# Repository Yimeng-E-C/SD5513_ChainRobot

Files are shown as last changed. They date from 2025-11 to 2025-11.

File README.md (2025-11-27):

# SD5513_ChainRobot
## 项目简介

**[ChainRobot]** 是一个用于 **[SD5513课程入门]** 的开源项目。  
本仓库包含完整的源代码、配置文件以及基础文档，方便开发者快速上手与二次开发。
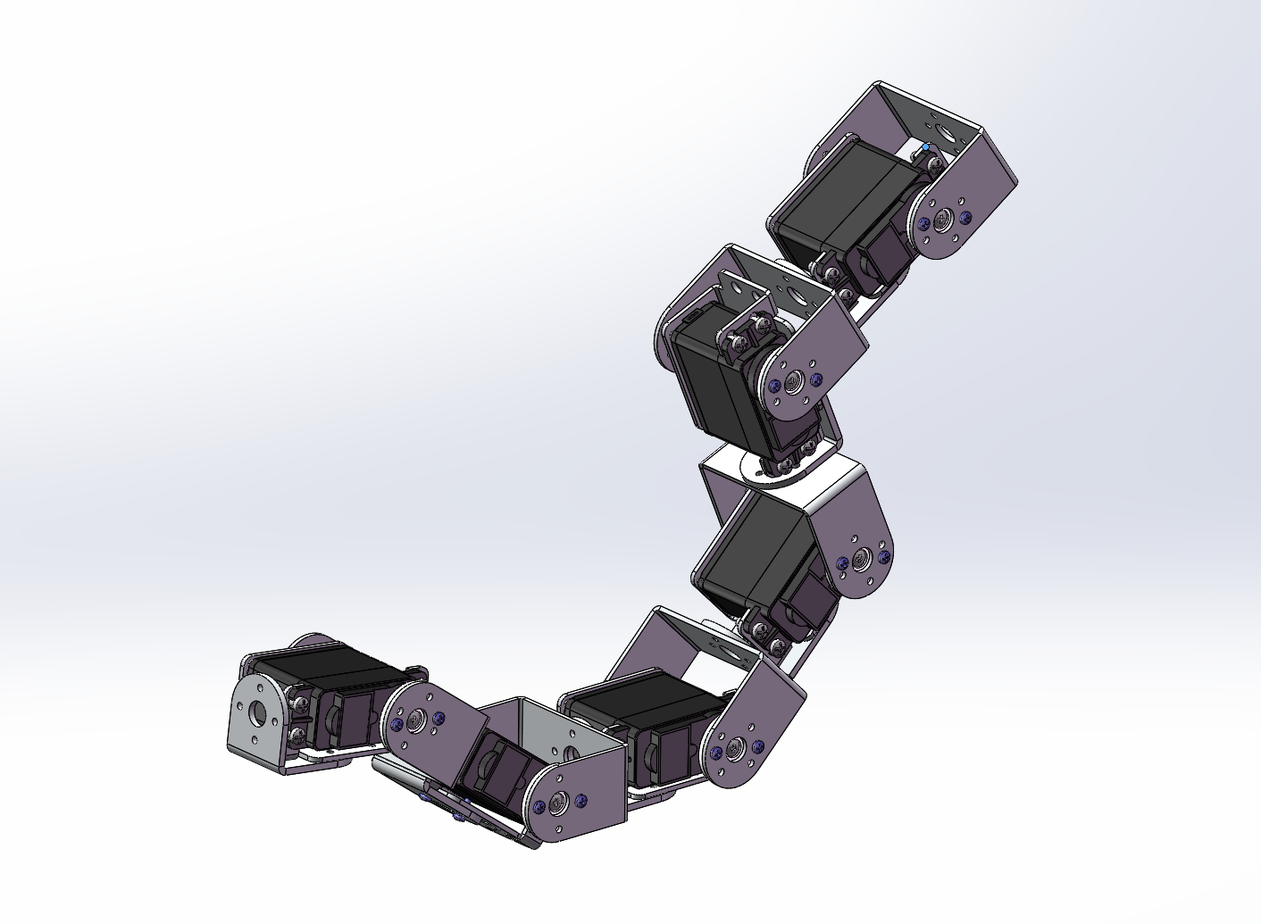
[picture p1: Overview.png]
Overview
- 

### 功能概览

- ✅ **核心功能 1**：用于 **[例如：数据处理 / 模型训练 / 设备控制等]**
- ✅ **核心功能 2**：支持 **[例如：可视化 / 实时监控 / 接口调用等]**
- ✅ **核心功能 3**：提供 **[例如：命令行工具 / Web 界面 / API 接口]**

### 技术栈

- 语言：**[例如：Python / JavaScript / C++ 等]**
- 框架 / 库：**[例如：PyTorch / React / Node.js / ROS 等]**
- 其他：**[例如：Docker / MQTT / REST API 等]**
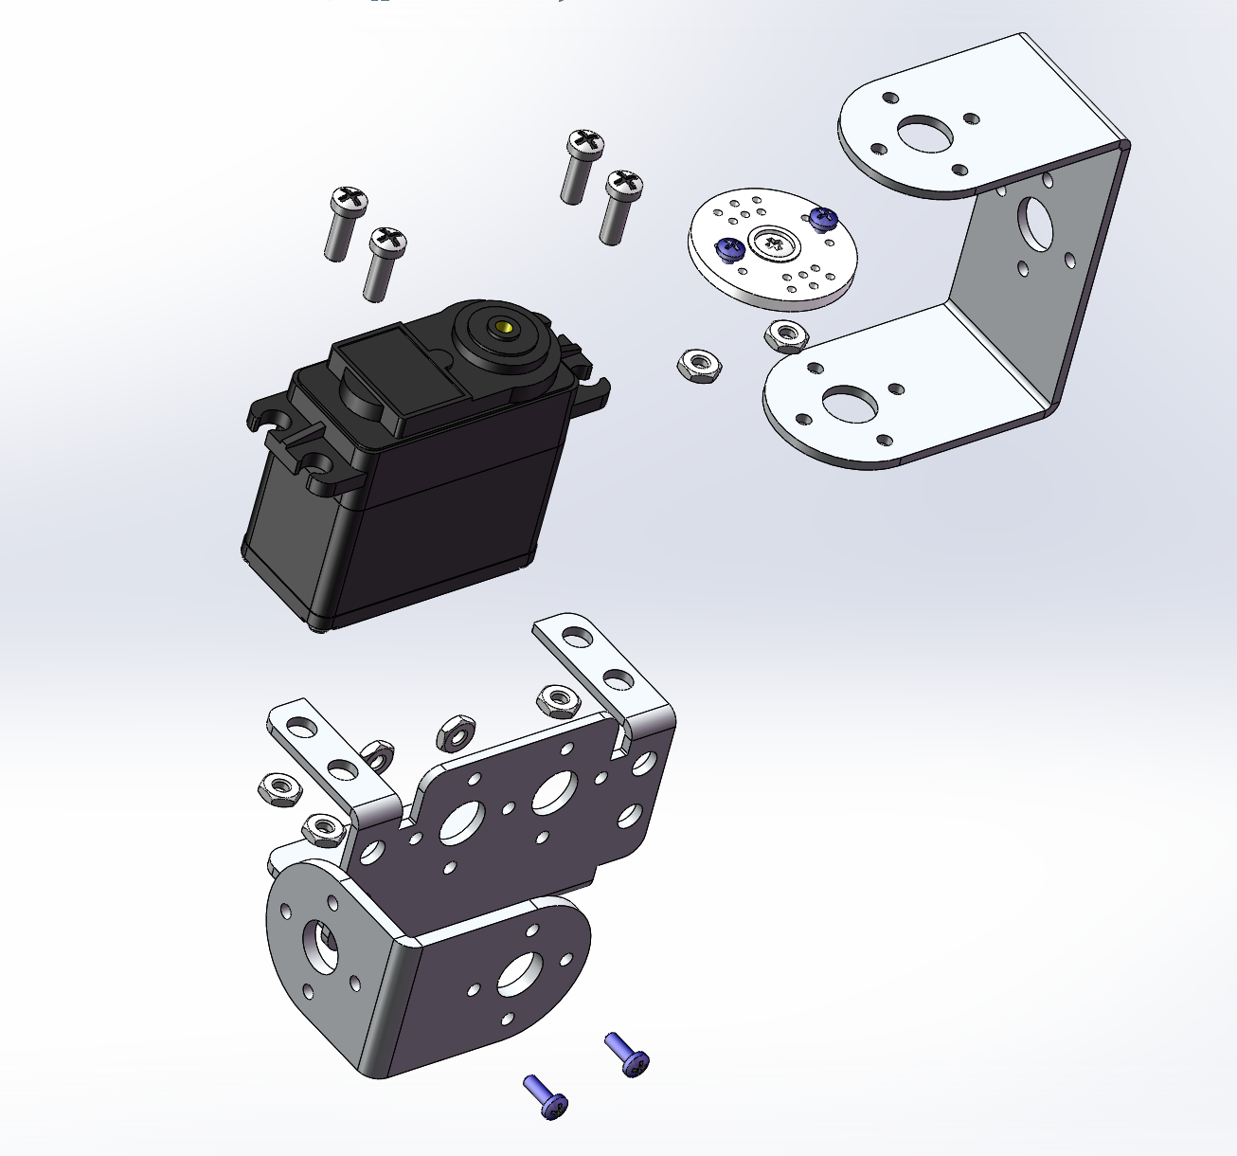
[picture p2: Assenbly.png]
Assenbly
- 

### 适用场景

本项目适用于：

- **[场景 1]**：如 *[示例]*  
- **[场景 2]**：如 *[示例]*  
- **[场景 3]**：如 *[示例]*  

### 快速开始

如果你想快速体验本项目，可以参考下方章节：

- 控制代码：见 **[Instruction / 指导]** 部分  
- 硬件组装：见 **[Models / Assenbly]** 部分  
- 更多细节：见 **[Docs / 文档链接或路径]**

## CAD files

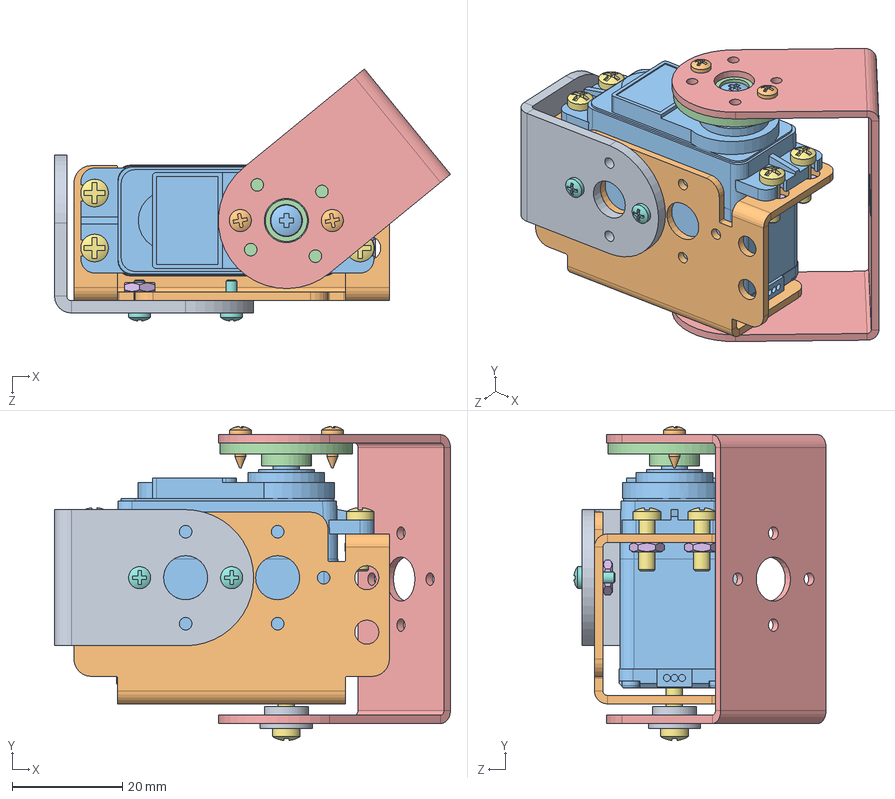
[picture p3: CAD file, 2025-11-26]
Models/Unit1.SLDASM
71.7 x 56.9 x 45.7 mm
Servo-HS-485HB
ASB-04
ASB-06
Bolt-01 x 2
Bolt-02 x 5
Nut-02 x 5
ASB-09
Servo-Dial
Servo-Screw
Screw-01 x 2
Ball-Bearing-01

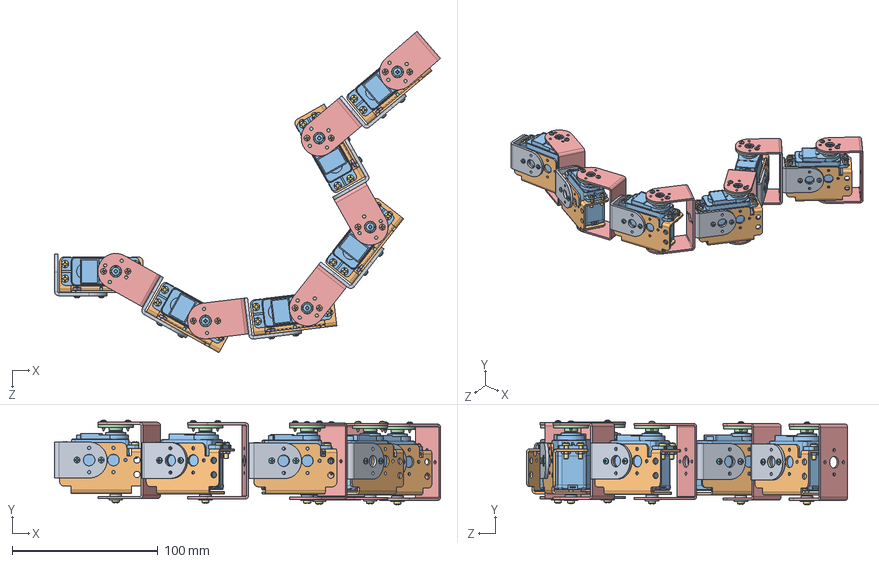
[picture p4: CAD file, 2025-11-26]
Models/SnakeRobot.SLDASM
264.6 x 58.1 x 220.4 mm
Servo-HS-485HB x 6
ASB-04 x 6
ASB-06 x 6
Bolt-01 x 12
Bolt-02 x 30
Nut-02 x 30
ASB-09 x 6
Servo-Dial x 6
Servo-Screw x 6
Screw-01 x 12
Ball-Bearing-01 x 6

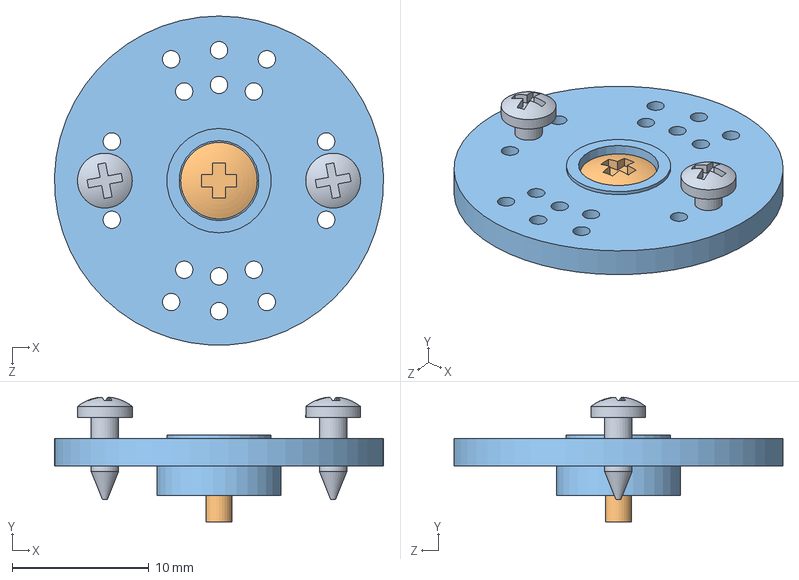
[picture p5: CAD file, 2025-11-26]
Models/SERVO-DIAL-ASSEMBLY.SLDASM
24.0 x 9.09 x 24.0 mm
Servo-Dial
Servo-Screw
Screw-01 x 2

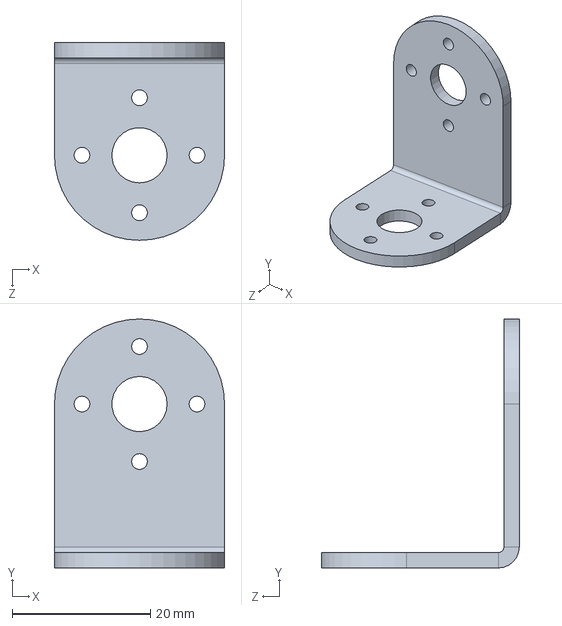
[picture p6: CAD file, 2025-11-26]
Models/ASB-06.SLDPRT
24.6 x 36.1 x 28.6 mm

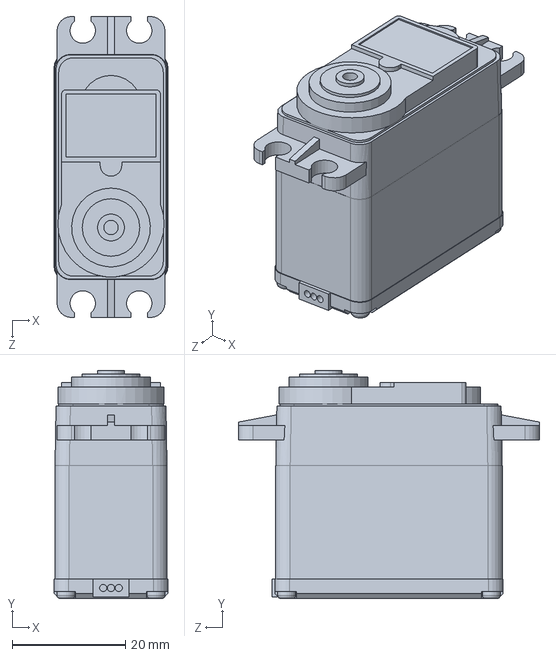
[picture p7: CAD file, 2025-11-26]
Models/Servo-HS-485HB.SLDPRT
20.1 x 40.2 x 53.1 mm

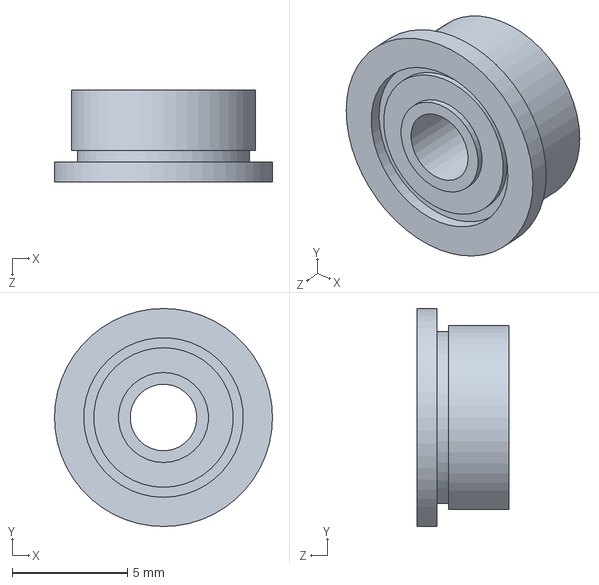
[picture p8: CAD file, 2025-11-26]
Models/Ball-Bearing-01.SLDPRT
9.47 x 9.47 x 3.99 mm

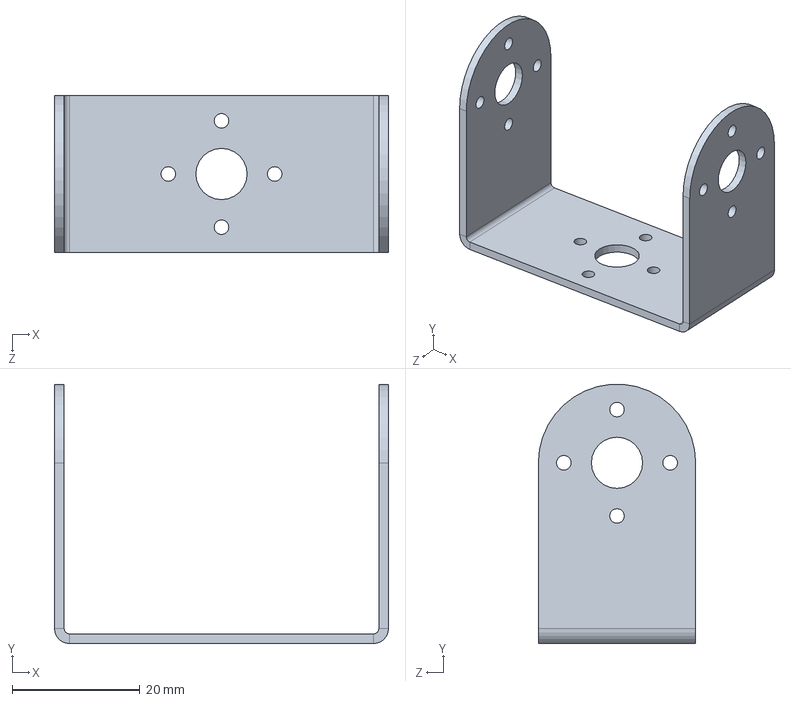
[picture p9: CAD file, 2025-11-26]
Models/ASB-09.SLDPRT
52.3 x 40.6 x 24.6 mm

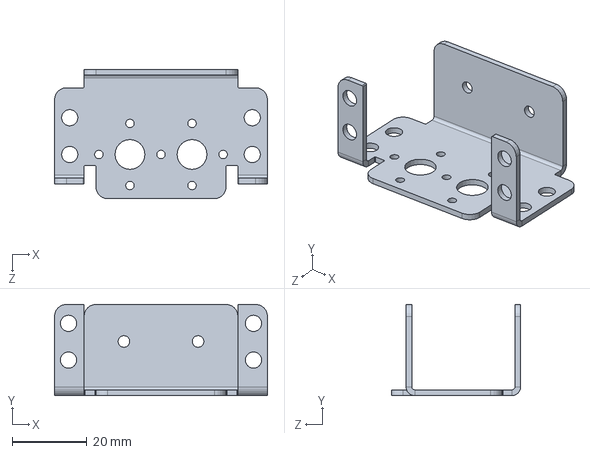
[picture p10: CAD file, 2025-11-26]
Models/ASB-04.SLDPRT
57.1 x 24.5 x 34.7 mm

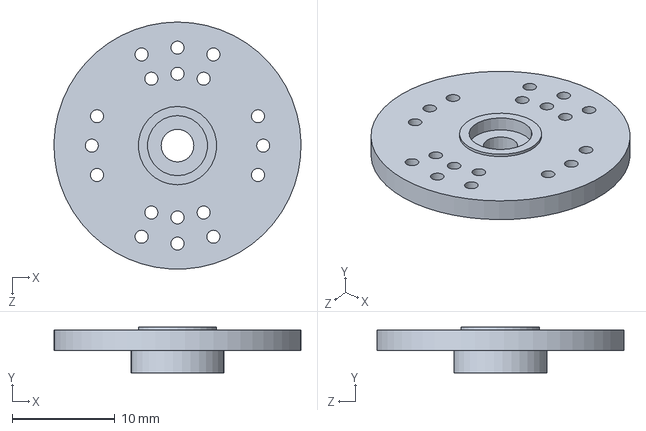
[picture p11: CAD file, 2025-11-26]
Models/Servo-Dial.SLDPRT
24.0 x 4.45 x 24.0 mm

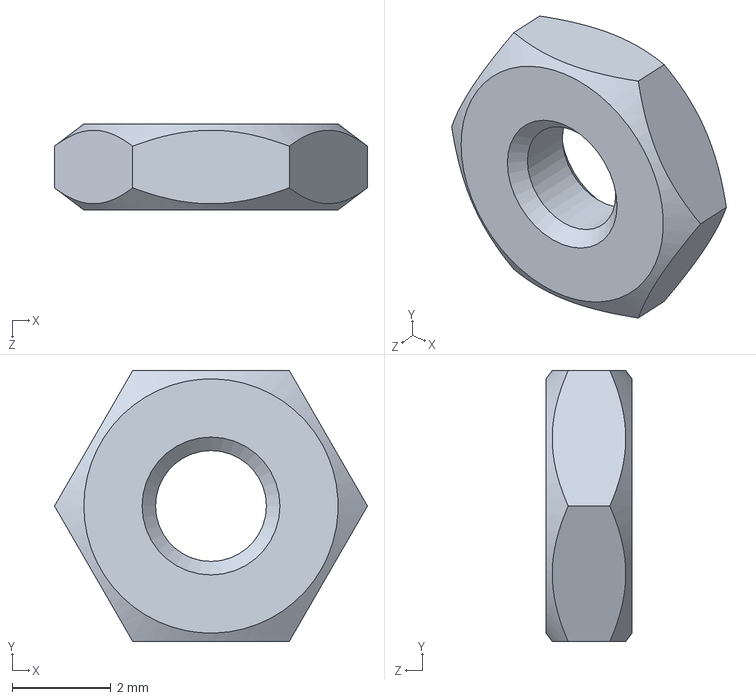
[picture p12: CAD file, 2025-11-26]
Models/Nut-02.SLDPRT
6.35 x 5.50 x 1.75 mm

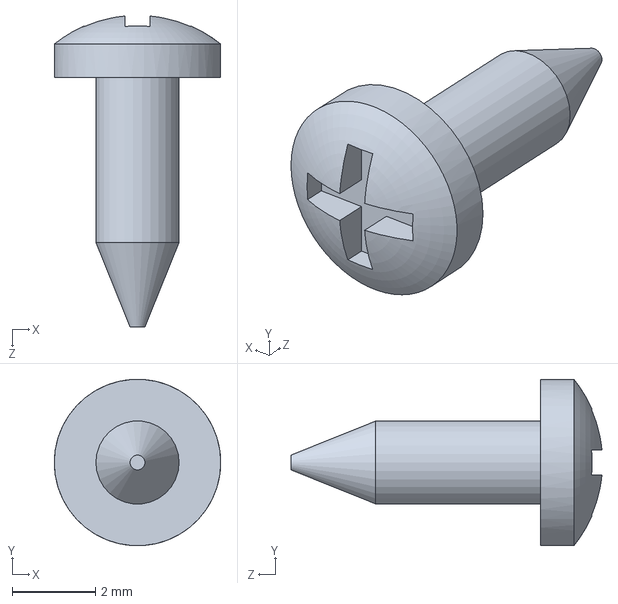
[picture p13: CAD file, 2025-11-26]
Models/Screw-01.SLDPRT
4.00 x 4.00 x 7.47 mm

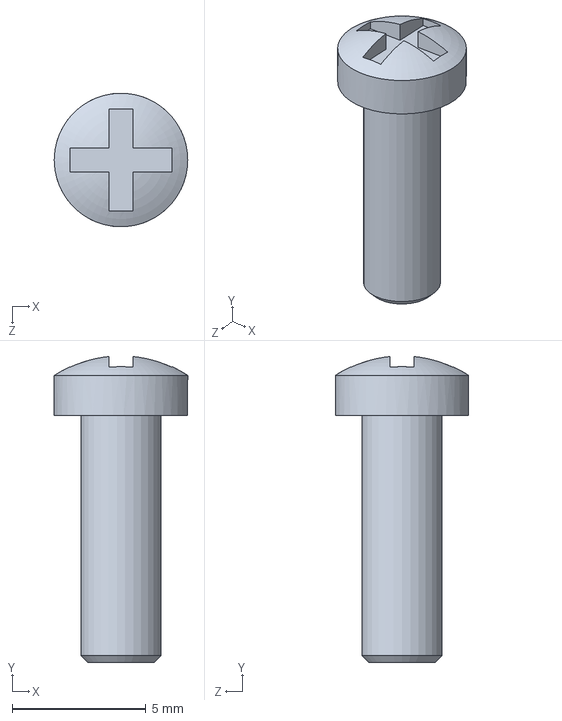
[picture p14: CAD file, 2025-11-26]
Models/Bolt-02.SLDPRT
5.00 x 11.5 x 5.00 mm

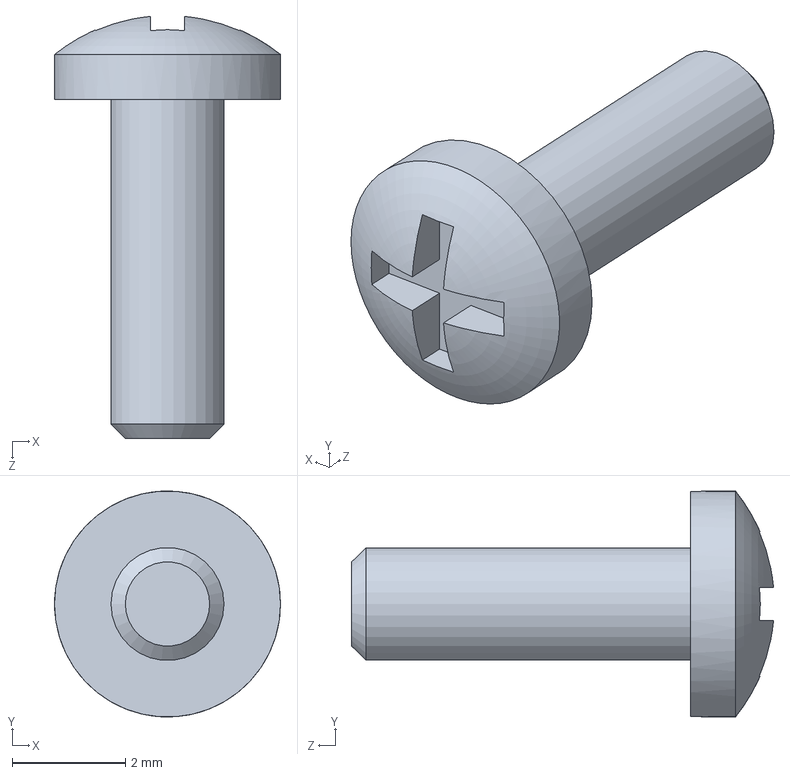
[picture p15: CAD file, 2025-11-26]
Models/Bolt-01.SLDPRT
4.00 x 4.00 x 7.47 mm

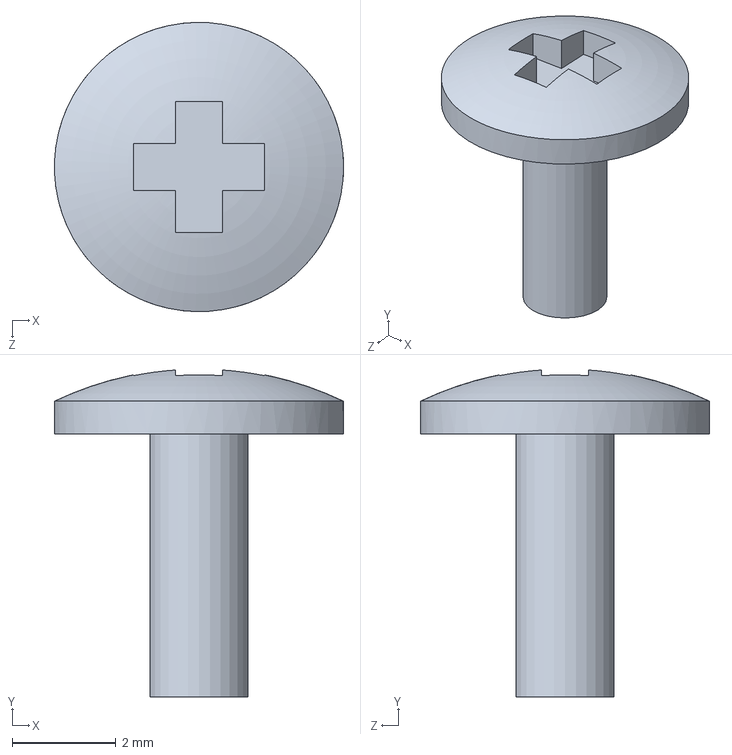
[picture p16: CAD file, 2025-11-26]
Models/Servo-Screw.SLDPRT
5.59 x 6.32 x 5.59 mm

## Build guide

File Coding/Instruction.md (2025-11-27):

6-DOF Snake Robot 主程序 README
本程序用于控制一条由 6 个舵机组成的蛇形机器人，通过 Arduino 串口输入不同按键，触发不同动作（直行爬行、转弯、尺蠖、U 形、环形等），并带有「复位到 90°」和「直线 home 姿态」功能，方便调试与教学。

1. 环境与依赖
1.1 硬件要求
Arduino 主控板
推荐：Arduino Uno / Arduino Nano（ATmega328P）
舵机（Servo）× 6
建议：9g 舵机，如 SG90（塑料齿）、MG90S（金属齿）等
外部 5V 舵机电源（非常重要）
例如：5V 3A DC 适配器 / 降压模块
若干杜邦线、USB 线（Type-A → Micro-USB / Mini-USB / USB-B，根据你的板子）
注意：请不要用 Arduino 板载的 5V 引脚直接给 6 个舵机供电，会导致板子复位甚至损坏。
1.2 软件要求
Arduino IDE（建议 1.8.x 或 2.x 版本）
串口监视器（Arduino IDE 自带）
1.3 所需库
本程序只需要 Servo 库（Arduino 官方自带）：
#include <Servo.h>
一般情况下，Arduino IDE 已经自带此库，无需另装。如果编译时报错找不到 Servo：
在菜单栏选择：Sketch → Include Library → Manage Libraries...
搜索 Servo，安装官方的 Servo 库即可。

2. 硬件接线说明
2.1 舵机与 Arduino 引脚对应关系
程序中默认使用 6 个数字引脚：
const int TotalNumberofServos = 6;
const int servoPins[TotalNumberofServos] = {2, 3, 4, 5, 6, 7};
推荐约定如下（你也可以在 README 里画图）：
舵机编号
位置建议（可自定义）
Arduino 引脚
Servo 0
尾部关节
D2
Servo 1
第 2 节
D3
Servo 2
第 3 节
D4
Servo 3
第 4 节
D5
Servo 4
第 5 节
D6
Servo 5
头部关节
D7
常见舵机线序：
棕/黑：GND（地）
红：5V（电源正）
黄/橙/白：信号（PWM）
2.2 电源接法（重点）
推荐使用独立 5V 电源给舵机供电：
舵机电源：
6 个舵机的 红线 → 外部 5V 电源的 +
6 个舵机的 棕/黑线 → 外部 5V 电源的 -
Arduino 与舵机电源共地：
将外部 5V 电源的 - → 接到 Arduino 的 GND 引脚
这样 Arduino 和舵机之间就共地了，信号才可靠。
舵机信号：
6 个舵机的 信号线 分别接：D2, D3, D4, D5, D6, D7
Arduino 供电：
Arduino 通过 USB 连接电脑供电 (Mac需使用拓展坞)。
总结：
舵机电流由外部 5V 电源提供；
Arduino 只提供逻辑信号；
一定要共地：电源 GND ↔ Arduino GND ↔ 所有舵机 GND。

3. 程序使用方法
3.1 烧录程序
打开 Arduino IDE
将主程序 SnakeControl.ino 文件打开
在 Tools 菜单中选择对应的板子和端口：
Board: Arduino Uno 或 Arduino Nano (ATmega328P, Old Bootloader) 等
Port: 对应你的 USB 口
点击“上传”（右箭头按钮）。
3.2 打开串口监视器
在 Arduino IDE 中点击右上角“串口监视器”图标；
设置：
波特率：115200
行结束符：可选 “None” 或 “Both NL & CR”（程序会忽略回车换行）
上电初始化后，串口会自动打印出一个菜单（帮助信息）。
3.3 串口按键与动作对应表
在串口监视器中输入 单个字符（不需要回车也可以），即可触发对应动作。
按键（串口输入）
对应动作 / 函数
r / R
rawReset90()：Raw Reset：所有舵机转到 90°，不加偏差（用于确认机械零位）
0
homePose()：根据 servoOffset 把蛇恢复到“直线姿态”
1
slither(0, 35, 2, 1.5)：直行蛇形爬行
2
slither(10, 35, 2, 1.5)：带右偏的蛇形爬行（右转趋势）
3
slither(-10, 35, 2, 1.5)：带左偏的蛇形爬行（左转趋势）
4
staticWave(0, 35, 1.5)：静态波形（1.5 个波长）
5
InchWorm()：尺蠖步态，从尾到头依次“拱起”
6
ubend()：U 形，机器人身体中间强弯
7
ring()：环形，近似绕成一个圈
8
Cshape()：C 形，整体向一侧弯曲
9
straightline()：拉直（内部调用 homePose()）
h / H
再次打印帮助菜单
推荐调试流程：
上电后，先按 r → 看所有关节能否都转到大致的中位；
再按 0 或 9 → 看整体是否是你想要的直线 home 姿态。

4. 代码结构与逻辑说明
4.1 全局配置与状态
主要全局变量：
const int TotalNumberofServos = 6;      // 舵机数量
Servo myServos[TotalNumberofServos];    // 舵机对象数组float pi = 3.14...相邻舵机之间的相位差（蛇形波）int servoPins[6] = {2, 3, 4, 5, 6, 7};  // 舵机信号引脚
// 每个舵机的零点偏差（软件校正用）int servoOffset[TotalNumberofServos] = {0, 0, 0, 0, 0, 0};
Shift 用于 slither() 和 staticWave() 函数，控制每个关节之间的相位差，使整条蛇形成连续波。
servoOffset[] 用来做软件层零点校正：机械上装好后，如果某一节总是有点偏，可以在这里微调。
4.2 工具函数
setAllServos(int angle)
不加任何偏差，直接把所有舵机打到同一个角度。
主要用于 Raw Reset、内部初始化等。
rawReset90()
调用 setAllServos(90)；
所有关节转到 90°，方便你观察机械零位。
homePose()
把每个舵机设置为 90 + servoOffset[i]；
这是你定义的“视觉直线姿态”，用来作为蛇的基准姿势。
applyHump(int baseIndex, int pos)
尺蠖步态内部用的“小拱形”生成函数；
以 baseIndex 为起点，在 3 个相邻舵机上形成 -1, 2, -1 的角度模式。
4.3 各种动作函数（gait primitives）
straightline()
调用 homePose()，把蛇复位回直线姿态。
Cshape()
将所有舵机设置为 60°，整体向一侧弯曲成 C 形（简单示范姿势）。
ubend()
计算中间关节（中间 1 或 2 个），设为 0°，其它为 90°；形成 U 形。
ring()
利用正多边形内角公式计算弯曲角度，让每一节弯得差不多，整体接近一个环。
slither(int offset, int Amplitude, int Speed, float Wavelengths)
关键蛇形 gait 函数：
时间上：随时间 t 变化的正弦项 sin(Speed * t + phase)；
空间上：每个关节相位差为 j * Wavelengths * Shift；
offset 控制整体偏置（用于左/右转弯）；
Amplitude 控制摆动幅度；
Speed 控制波传播速度；
Wavelengths 控制整条蛇上铺了多少个波长。
staticWave(int offset, int Amplitude, float Wavelengths)
只在空间上有波形，不随时间变化；常用于展示不同弯曲造型。
InchWorm()
利用 applyHump() 在身体上从尾到头依次“滚动”一个小拱，模仿尺蠖的前进方式。
4.4 串口菜单与控制逻辑
printHelp()
在串口打印所有可用命令和说明。
handleKey(char c)
根据收到的单个字符 c 选择对应 gait 函数；
包含对 r、0、1～9、h 的处理。
setup()
初始化串口：Serial.begin(115200)；
计算 Shift = 2 * pi / TotalNumberofServos；
附加各个 Servo 到对应引脚；
调用 homePose() 做一次上电复位；
打印帮助菜单。
loop()
检查 Serial.available()；
有数据就读取一个字符：
如果是 \n 或 \r，忽略；
否则丢给 handleKey(c) 处理。
各个动作函数内部都包含自己的 delay()，因此 loop 本身是事件驱动而非周期调度。

5. 校准与调试建议
初次装配后：
烧录主程序；
通电 → 串口输入 r（Raw Reset）→ 所有关节转到 90°；
观察蛇是否大致成直线，如不直，可以卸下个别舵臂重新插。
微调零点偏差：
如果某一节还是偏一点点，可以修改：
int servoOffset[6] = {0, 0, 0, 0, 0, 0};
例如改成 {0, 2, -3, 0, 1, 0}，再重新上传程序；
然后按 0 或 9 看 Home 姿态是否直了。
动作测试顺序：
先测试静态动作：6（U 形）、7（ring）、8（C 形）、9（直线）；
再试动态动作：1～5，观察是否有卡爪、线缠绕等问题。
如出现舵机抖动严重、温度异常升高，请减小 Amplitude 或检查舵机电源是否足够。

6. 后续扩展（面向 LLM / 远程控制）
虽然当前版本只通过串口手动输入字符控制动作，但程序结构已经为后续扩展预留空间：
可以在 loop() 中改为解析完整字符串命令（例如 SLITHER 0 35 2 1.5~）；
由 PC / Node-RED / LLM 生成这些命令，通过 USB 串口发送给 Arduino；
Arduino 只需把 handleKey 的逻辑扩展为 handleCommandString(String cmd) 即可。
这样，当前 README 和主程序既可以作为单独的实验，也可以作为后续“LLM + Snake”大项目的底层控制模块。

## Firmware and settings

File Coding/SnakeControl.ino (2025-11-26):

#include <Servo.h>

// =================== 基本参数 ===================
const int TotalNumberofServos = 6;      // 6 个舵机

Servo myServos[TotalNumberofServos];

float pi = 3.14159;
float Shift;                            // 相邻关节之间的相位差
int InteriorAngle, SetpointAngle, MaxAngleDisplacement;

// 根据实际接线改这里：6 个舵机信号线对应的引脚
const int servoPins[TotalNumberofServos] = {
  2, 3, 4, 5, 6, 7
};

// 每个舵机的零点偏差（单位：度），之后可以按需要微调
int servoOffset[TotalNumberofServos] = {0, 0, 0, 0, 0, 0};

// =================== 工具函数 ===================

// 所有舵机设为同一个角度（不加偏差）
void setAllServos(int angle) {
  for (int i = 0; i < TotalNumberofServos; i++) {
    myServos[i].write(angle);
  }
}

// Raw Reset：全部打到 90°（机械中位，不加偏差）
void rawReset90() {
  setAllServos(90);
}

// Home 姿态：直线 + 软件偏差
void homePose() {
  for (int i = 0; i < TotalNumberofServos; i++) {
    int target = 90 + servoOffset[i];
    if (target < 0) target = 0;
    if (target > 180) target = 180;
    myServos[i].write(target);
  }
}

// 尺蠖用的小“拱”
void applyHump(int baseIndex, int pos) {
  const int humpSize = 3;
  const int pattern[humpSize] = { -1, 2, -1 };

  // 先拉直到 90°
  rawReset90();

  for (int k = 0; k < humpSize; k++) {
    int idx = baseIndex + k;
    if (idx >= 0 && idx < TotalNumberofServos) {
      int angle = 90 + pattern[k] * pos;
      if (angle < 0) angle = 0;
      if (angle > 180) angle = 180;
      myServos[idx].write(angle);
    }
  }
}

// =================== 各种动作 ===================

// 1. 直线（用 Home 姿态）
void straightline() {
  homePose();
}

// 2. C 形（全部往一侧偏）
void Cshape() {
  setAllServos(60);
}

// 3. U 形：中间几节强弯
void ubend() {
  int mid1, mid2;
  if (TotalNumberofServos % 2 == 0) {
    mid1 = TotalNumberofServos / 2 - 1;
    mid2 = TotalNumberofServos / 2;
  } else {
    mid1 = TotalNumberofServos / 2;
    mid2 = -1;
  }

  for (int i = 0; i < TotalNumberofServos; i++) {
    if (i == mid1 || i == mid2) {
      myServos[i].write(0);
    } else {
      myServos[i].write(90);
    }
    delay(50);
  }
}

// 4. 环形：弯成接近闭环的多边形
void ring() {
  InteriorAngle = 180 - 360 / (TotalNumberofServos + 1);
  SetpointAngle = abs(InteriorAngle - 90);
  for (int i = 0; i < TotalNumberofServos; i++) {
    myServos[i].write(SetpointAngle);
    delay(50);
  }
}

// 5. 蛇形爬行 slither
void slither(int offset, int Amplitude, int Speed, float Wavelengths) {
  MaxAngleDisplacement = abs(offset) + abs(Amplitude);

  // 确保不会超过 [0,180]
  while (MaxAngleDisplacement > 90) {
    Amplitude = abs(Amplitude) - 1;
    MaxAngleDisplacement = abs(offset) + Amplitude;
  }

  for (int i = 0; i < 360; i++) {
    float rads = i * pi / 180.0;

    for (int j = 0; j < TotalNumberofServos; j++) {
      float angle = 90 + offset +
                    Amplitude * sin(Speed * rads + j * Wavelengths * Shift);
      if (angle < 0) angle = 0;
      if (angle > 180) angle = 180;
      myServos[j].write((int)angle);
    }
    delay(10);
  }
}

// 6. 静态波形 staticWave
void staticWave(int offset, int Amplitude, float Wavelengths) {
  MaxAngleDisplacement = abs(offset) + abs(Amplitude);

  while (MaxAngleDisplacement > 90) {
    Amplitude = abs(Amplitude) - 1;
    MaxAngleDisplacement = abs(offset) + Amplitude;
  }

  for (int j = 0; j < TotalNumberofServos; j++) {
    float angle = 90 + offset +
                  Amplitude * sin(j * Wavelengths * Shift);
    if (angle < 0) angle = 0;
    if (angle > 180) angle = 180;
    myServos[j].write((int)angle);
    delay(15);
  }
}

// 7. 尺蠖步态 InchWorm
void InchWorm() {
  const int humpSize = 3;
  const int maxPos   = 30;

  for (int base = 0; base <= TotalNumberofServos - humpSize; base++) {
    for (int pos = 0; pos <= maxPos; pos++) {
      applyHump(base, pos);
      delay(10);
    }
  }

  homePose();
  delay(200);
}

// =================== 串口菜单相关 ===================

void printHelp() {
  Serial.println(F("===== Snake Robot 控制菜单 ====="));
  Serial.println(F("r: Raw Reset, 所有舵机到 90 度（无偏差）"));
  Serial.println(F("0: Home 复位到直线 (90+偏差)"));
  Serial.println(F("1: slither 直行"));
  Serial.println(F("2: slither 右转"));
  Serial.println(F("3: slither 左转"));
  Serial.println(F("4: staticWave 1.5 波长"));
  Serial.println(F("5: InchWorm 尺蠖步态"));
  Serial.println(F("6: U 形 (ubend)"));
  Serial.println(F("7: 圈形 (ring)"));
  Serial.println(F("8: C 形 (Cshape)"));
  Serial.println(F("9: 拉直 (straightline = Home)"));
  Serial.println(F("h: 再次打印帮助"));
  Serial.println(F("================================"));
}

// 根据输入字符执行动作
void handleKey(char c) {
  switch (c) {
    case 'r':
    case 'R':
      Serial.println(F("[动作] Raw Reset: 所有舵机到 90 度（无偏差）"));
      rawReset90();
      break;

    case '0':
      Serial.println(F("[动作] Home: 复位到直线 (带偏差)"));
      homePose();
      break;

    case '1':
      Serial.println(F("[动作] slither 直行"));
      slither(0, 35, 2, 1.5);
      break;

    case '2':
      Serial.println(F("[动作] slither 右转"));
      slither(10, 35, 2, 1.5);
      break;

    case '3':
      Serial.println(F("[动作] slither 左转"));
      slither(-10, 35, 2, 1.5);
      break;

    case '4':
      Serial.println(F("[动作] staticWave 1.5 波长"));
      staticWave(0, 35, 1.5);
      break;

    case '5':
      Serial.println(F("[动作] InchWorm 尺蠖步态"));
      InchWorm();
      break;

    case '6':
      Serial.println(F("[动作] U 形 ubend"));
      ubend();
      break;

    case '7':
      Serial.println(F("[动作] 圈形 ring"));
      ring();
      break;

    case '8':
      Serial.println(F("[动作] C 形 Cshape"));
      Cshape();
      break;

    case '9':
      Serial.println(F("[动作] 拉直 straightline (Home)"));
      straightline();
      break;

    case 'h':
    case 'H':
      printHelp();
      break;

    default:
      Serial.println(F("未知命令，输入 h 查看帮助"));
      break;
  }
}

// =================== Arduino 标准入口 ===================

void setup() {
  Serial.begin(115200);

  // 计算相位差
  Shift = 2 * pi / TotalNumberofServos;

  // 绑定舵机引脚
  for (int i = 0; i < TotalNumberofServos; i++) {
    myServos[i].attach(servoPins[i]);
  }

  // 上电后先复位到 Home 姿态
  homePose();
  delay(1000);

  printHelp();
}

void loop() {
  if (Serial.available() > 0) {
    char c = Serial.read();
    if (c == '\n' || c == '\r') {
      return;  // 忽略换行
    }
    handleKey(c);
  }
}
